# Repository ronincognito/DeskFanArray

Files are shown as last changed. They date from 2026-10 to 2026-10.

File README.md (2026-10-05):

# DeskFanArray

A 3D-printed bar of six PWM case fans, driven by an ESP32-S3 with a built-in touch display. Pick an airflow pattern on the screen, such as a gentle breeze, a travelling wave or a pulse, and the fans do the rest.

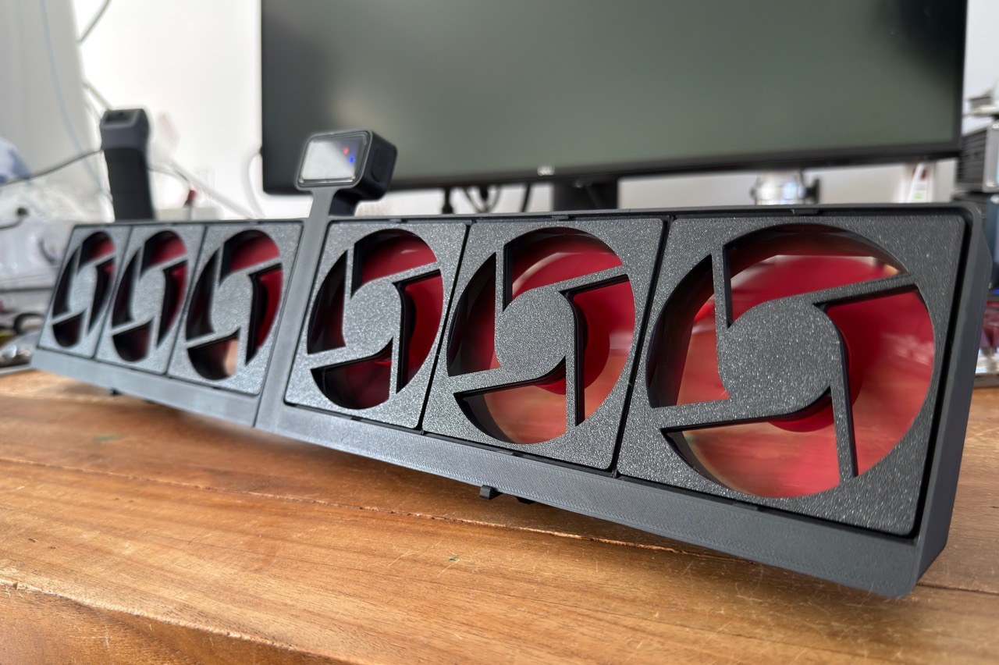
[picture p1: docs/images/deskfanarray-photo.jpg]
The finished DeskFanArray


Full project document (wiring, UI design, parts): [docs/README.pdf](docs/README.pdf)

## Features

- **Six 80 mm fans** with independent PWM speed control (any PWM fan works)
- **Touch UI** on a Waveshare ESP32-S3 1.47" display board, with seven screens, one per mode
- **Fully 3D-printed housing**, designed in Fusion 360
- **Single 12 V input** (match your fans' voltage); a buck converter makes the 5 V for the controller
- **Arduino firmware** with a configurable startup screen

## Control UI

The display has seven screens, one per mode. The dots at the bottom show which screen you are on. The six grey bars mirror the current speed of each fan; the coloured controls set the parameters of the active mode.

| breeze | wave |
|---|---|
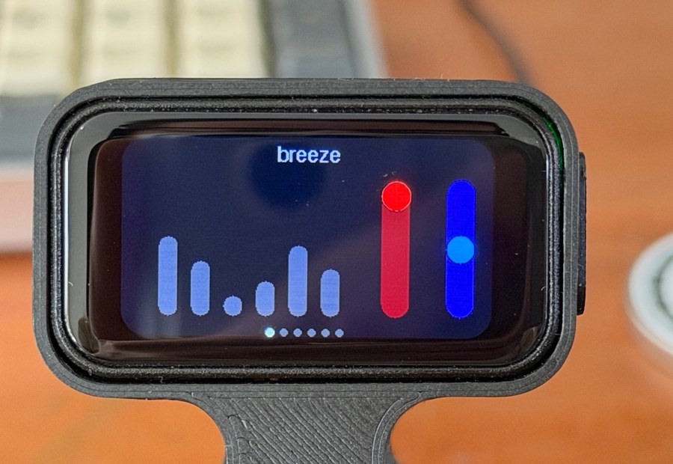
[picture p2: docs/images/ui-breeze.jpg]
breeze screen
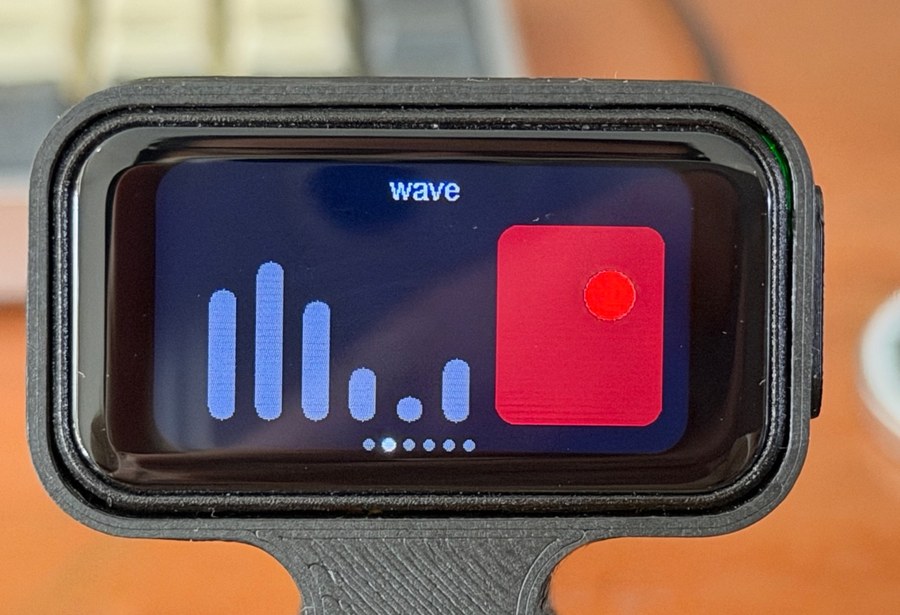
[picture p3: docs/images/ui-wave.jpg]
wave screen
|  |  |

| Screen | Controls |
|---|---|
| breeze | Two sliders: *peak gust* (red) and *gustiness* (blue) |
| wave | 2D pad for *wave height* and *direction* |
| monotone | One slider sets all fans to the same speed |
| stereotone | Two sliders, one for each half of the array |
| custom | Six sliders, one per fan |
| pulse | Two sliders (red and amber) for the pulsing pattern |

**Default screen:** press and hold (`longPress`) on a control screen to make it the default. On power-up, that screen is shown first.

The complete UI design sketch is in [docs/images/ui-overview.png](docs/images/ui-overview.png).

## Hardware

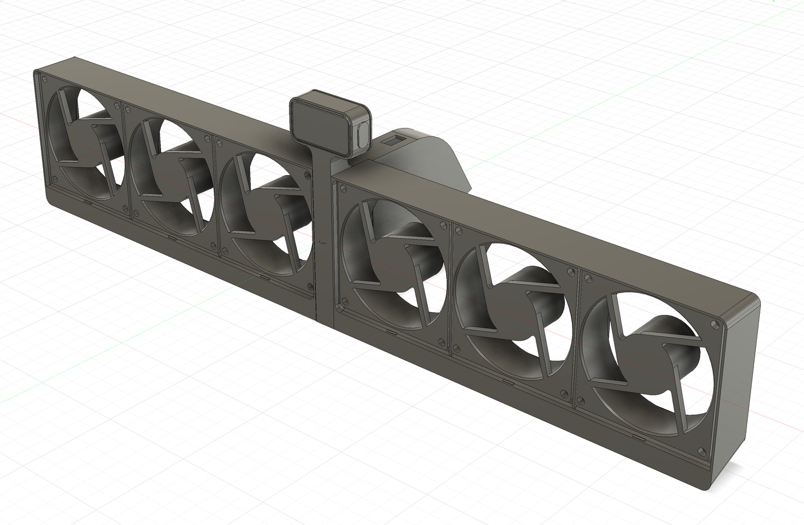
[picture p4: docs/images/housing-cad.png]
CAD model of the housing


| Part | Notes |
|---|---|
| ESP32-S3 touch LCD, 1.47" | Waveshare board; runs the UI and generates the six PWM signals |
| 6 x 80x80 mm PWM case fans | Xilence XPF80.R PWM in this build (12 V). Each fan's PWM wire goes to its own GPIO pin |
| Buck converter | 12 V in, 5 V out; powers the ESP board |
| 12 V DC supply | Powers the fans directly and the controller via the buck converter |
| On/off toggle switch | Mounted on the case behind the display; switches the +12 V line to both the buck converter and the fans |
| 3D-printed housing | Two case halves and a midsection, from the Fusion 360 model |
| 4 x M3 bolts + nuts | Mount the two case halves to the midsection |
| 4 x M2 bolts | Mount the controller to the midsection |

Any fan will do as long as it accepts a PWM input. If your fans need a voltage other than 12 V, adapt the supply voltage accordingly, and make sure the buck converter accepts that input voltage and still delivers 5 V to the controller.

## Wiring

The 12 V supply passes through the on/off toggle switch, which feeds the 12 V rail for the six fans and the buck converter. All fans share a common ground with the ESP board. The buck converter drops 12 V to 5 V for the controller, and six GPIO pins send PWM signals to the fans.

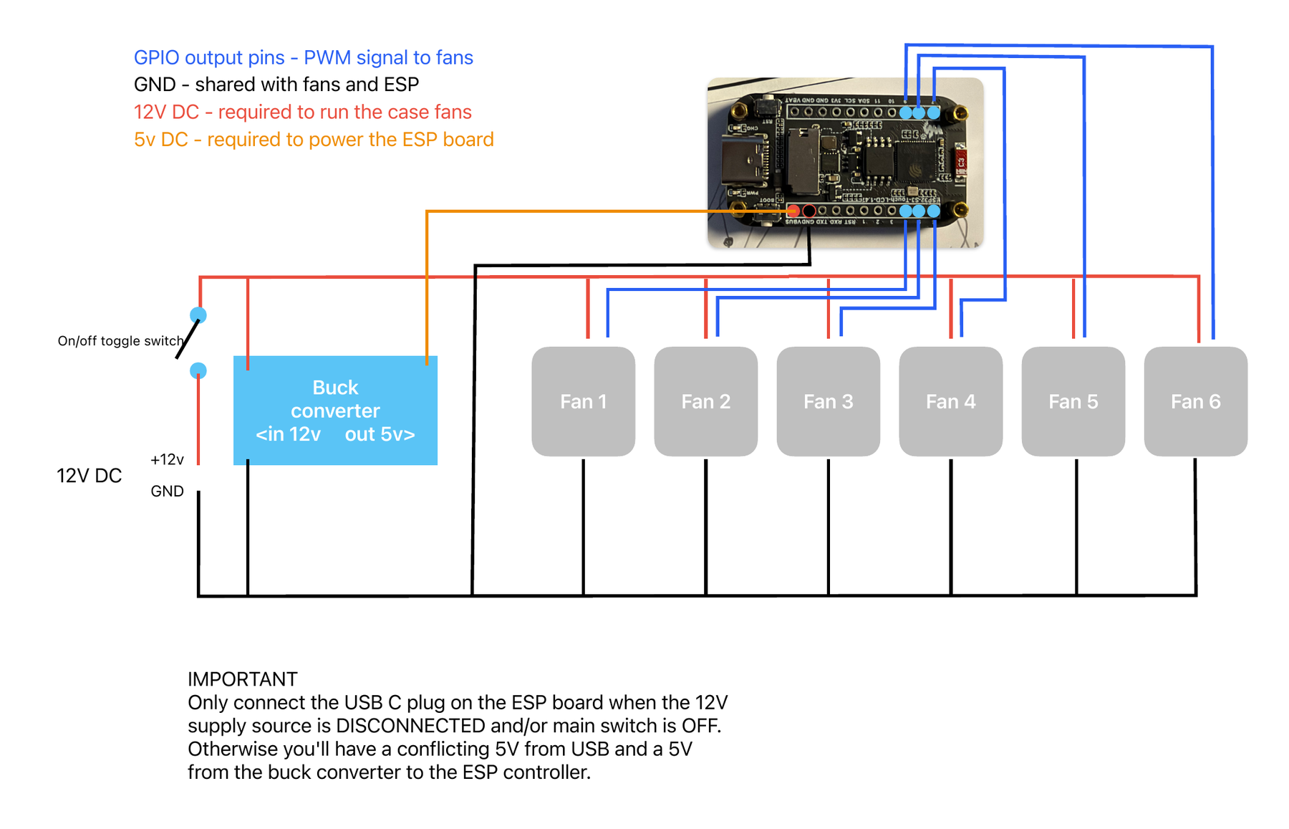
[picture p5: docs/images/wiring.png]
Wiring diagram


> **IMPORTANT:** Only connect the USB-C plug on the ESP board when the 12 V supply is disconnected and/or the main switch is OFF. Otherwise the board receives a conflicting 5 V from USB and from the buck converter.

## Repository layout

```
DeskFanArray/
  docs/                      wiring diagram, UI design, board photo, project PDF
  models/Fusion/             Fusion 360 housing model
  src/DeskFanController/
    DeskFanController.ino    firmware
    startup_image.h          startup image data
```

## Build and flash

1. Open `src/DeskFanController/DeskFanController.ino` in the Arduino IDE.
2. Select the Waveshare ESP32-S3 touch LCD 1.47" board (ESP32-S3 core) and the matching USB port.
3. Disconnect the 12 V supply (see the warning above), connect USB-C, and upload.
4. Disconnect USB, then power the unit from the 12 V supply.

## License

Released under the [MIT License](LICENSE). Copyright (c) 2026 ronincognito.

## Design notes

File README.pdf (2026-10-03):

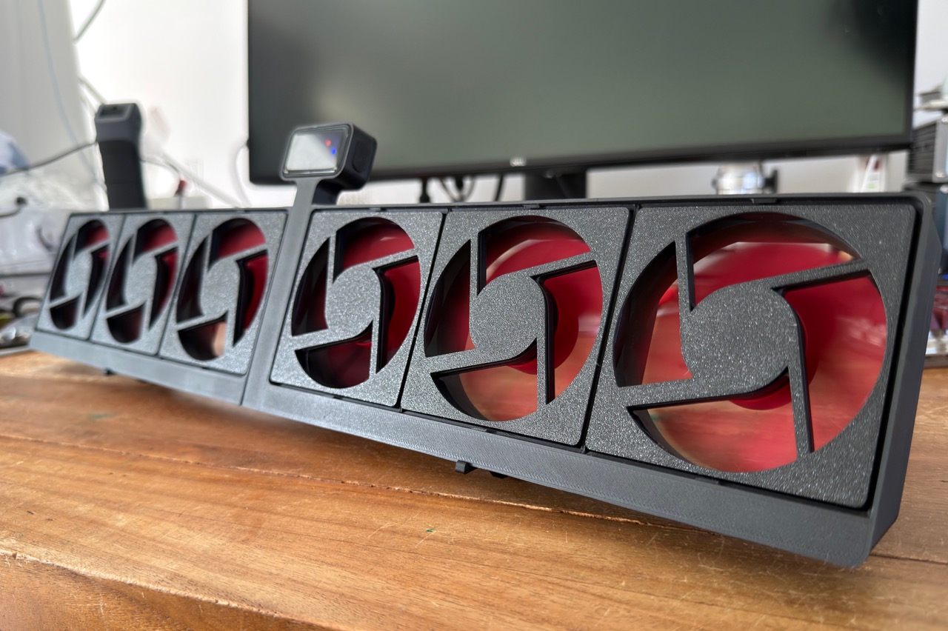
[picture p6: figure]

DeskFanArray | github.com/ronincognito/DeskFanArray | 1

# DeskFanArray

### A 3D-printed bar of six PWM case fans, driven by an ESP32-S3 with a built-in touch

display. Pick an airflow pattern on the screen, such as a gentle breeze, a travelling wave or a pulse, and the fans do the rest.

The finished build: six 12 V fans in a printed housing, with the controller display on a stalk in the middle.

## Overview

DeskFanArray combines six individually controlled fans in one long housing that sits on a desk. A small touch screen on a stalk lets you switch between control modes and adjust their parameters with sliders and a 2D pad. Each fan gets its own PWM signal, so patterns can move across the array instead of simply running all fans at the same speed.
- Six fans with independent PWM speed control (12 V case fans).
- Touch UI on a Waveshare ESP32-S3 1.47" display board, with seven screens, one per mode.
- Fully printed housing, designed in Fusion 360.
- Single 12 V input; a buck converter makes the 5 V for the controller.
- Arduino firmware (.ino) with a configurable startup screen.

## Control UI

The display shows seven screens, one per mode. The dots at the bottom show where you are. The six grey bars mirror the current speed of each fan. The red and blue controls set the parameters of the active mode.

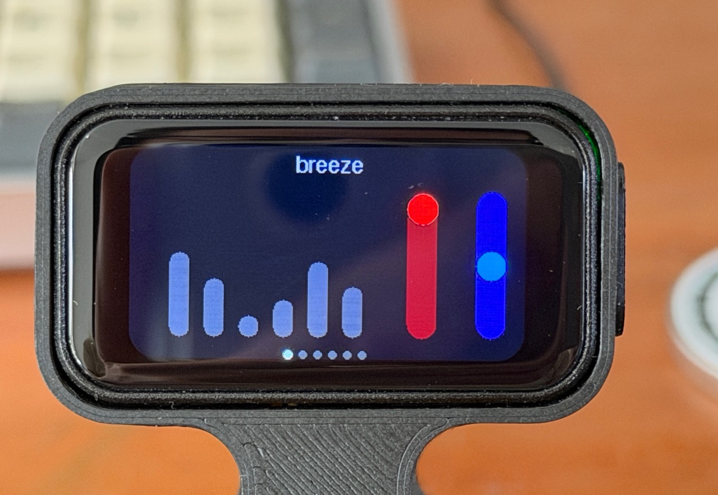
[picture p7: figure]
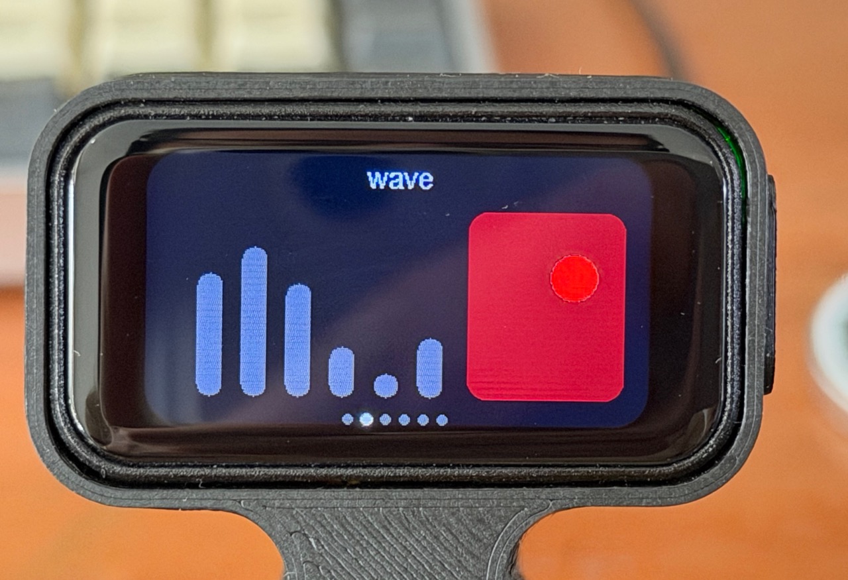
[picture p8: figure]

breeze: two sliders shape the airflow (red and blue). | wave: a 2D pad sets wave height and direction.
Screen | Controls (from the UI design)
breeze | Two sliders: peak gust (red) and gustiness (blue)
wave | 2D pad for wave height and direction; can be set as the startup screen
monotone | One slider sets all fans to the same speed
stereotone | Two sliders, one for each half of the array (left three, right three fans)
custom | Six sliders, one per fan
pulse | Two sliders (red and amber) for the pulsing pattern

Any screen can be chosen as the startup screen; the design on the next page shows wave set as the startup screen.

## UI design overview

Design sketch of all screens (Sketch file in docs/). Left column: breeze, wave, monotone, stereotone, custom, pulse. Right column: the wave startup-screen setting and the sub-screens for wave height/direction, peak gust and gustiness.

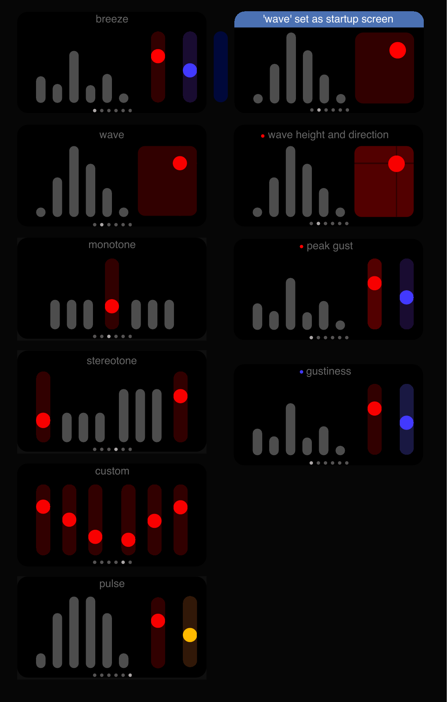
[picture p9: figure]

## Hardware

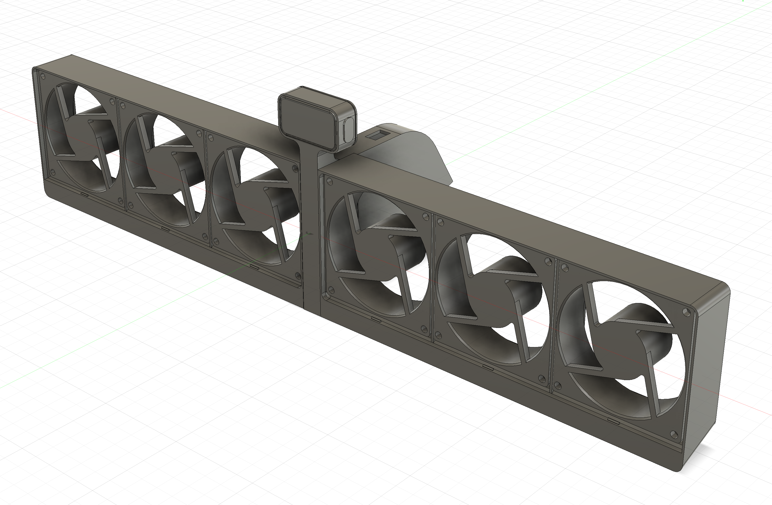
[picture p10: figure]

CAD model of the housing in Fusion 360 (file in models/Fusion/).

Part | Notes
ESP32-S3 touch LCD, 1.47" | Waveshare board; runs the UI and generates the six PWM signals
6 x 12 V PWM case fans | Each fan's PWM wire goes to its own GPIO pin
Buck converter | 12 V in, 5 V out; powers the ESP board
12 V DC supply + switch | Main switch on the +12 V line
3D-printed housing | Printed parts from the Fusion 360 model

## Wiring

All fans share the 12 V rail and a common ground with the ESP board. The buck converter drops 12 V to 5 V for the controller, and six GPIO pins send PWM signals to the fans.

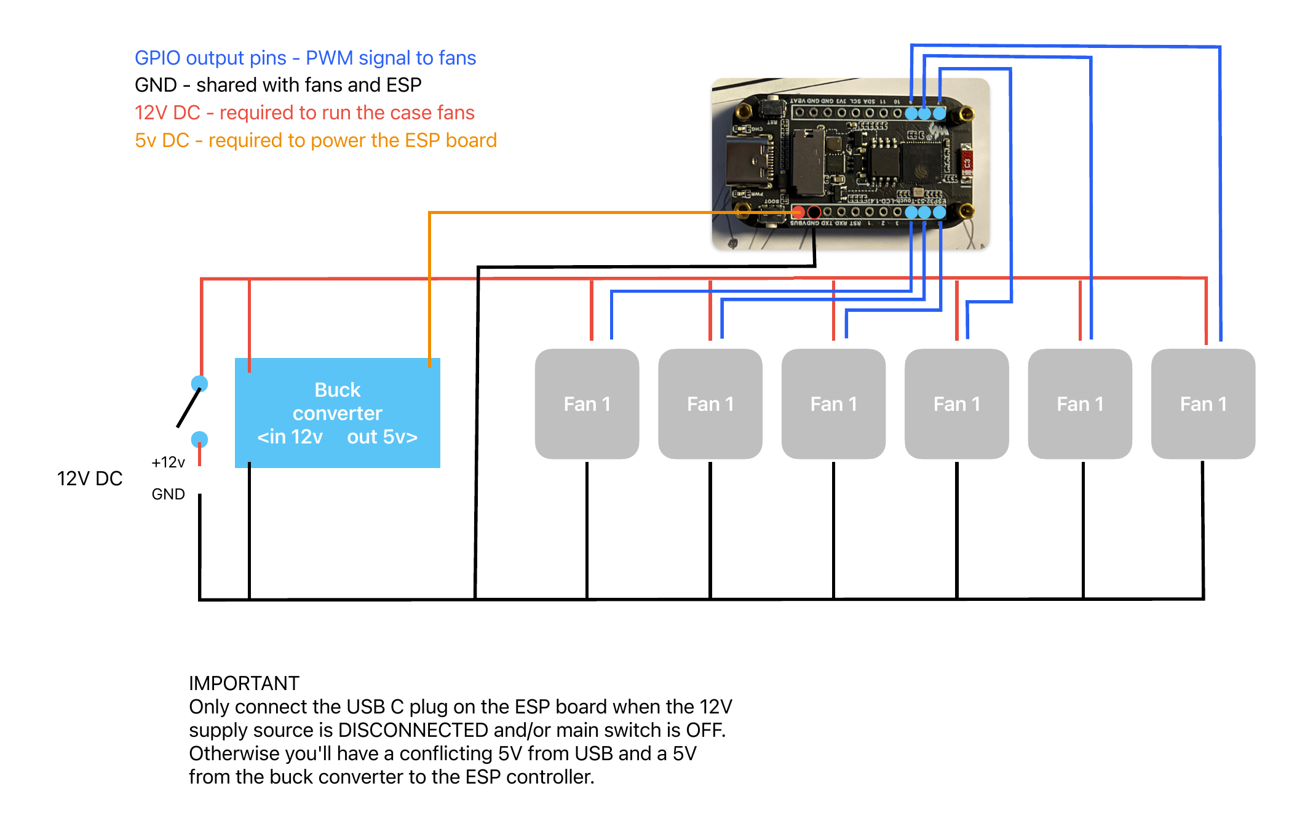
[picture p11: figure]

Wiring diagram (PDF in docs/). Blue: PWM signals. Black: ground. Red: 12 V. Orange: 5 V.

IMPORTANT
Only connect the USB-C plug on the ESP board when the 12 V supply is disconnected and/or the main switch is OFF. Otherwise the board receives a conflicting 5 V from USB and from the buck converter.

## Repository layout

DeskFanArray/
docs/ | wiring diagram, UI design (Sketch), board photo, notes
models/ | Fusion 360 housing model
src/DeskFanController/
DeskFanController.ino firmware
startup_image.h | startup image data

## Build and flash

- Open src/DeskFanController/DeskFanController.ino in the Arduino IDE.
- Select the Waveshare ESP32-S3 touch LCD 1.47" board (ESP32-S3 core) and the matching USB port.
- Disconnect the 12 V supply (see the warning above), connect USB-C, and upload.
- Disconnect USB, then power the unit from the 12 V supply.

Licence: not yet specified.

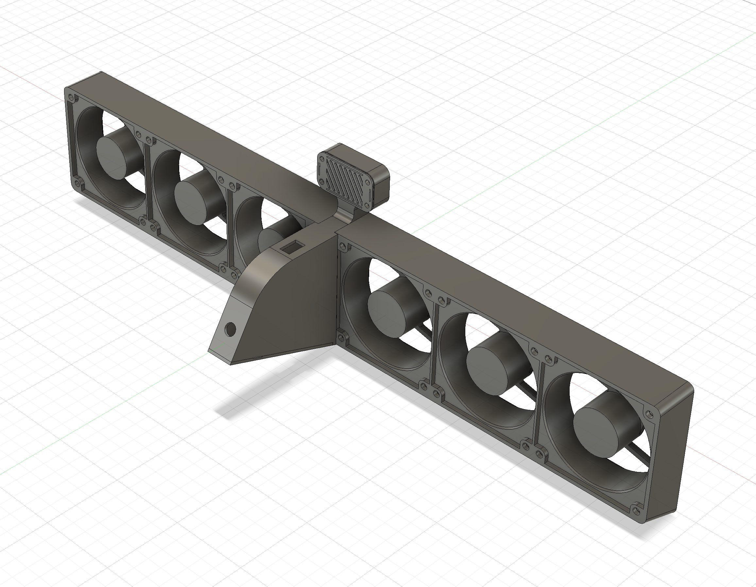
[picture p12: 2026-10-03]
docs/product design/Fusion Backside view.png

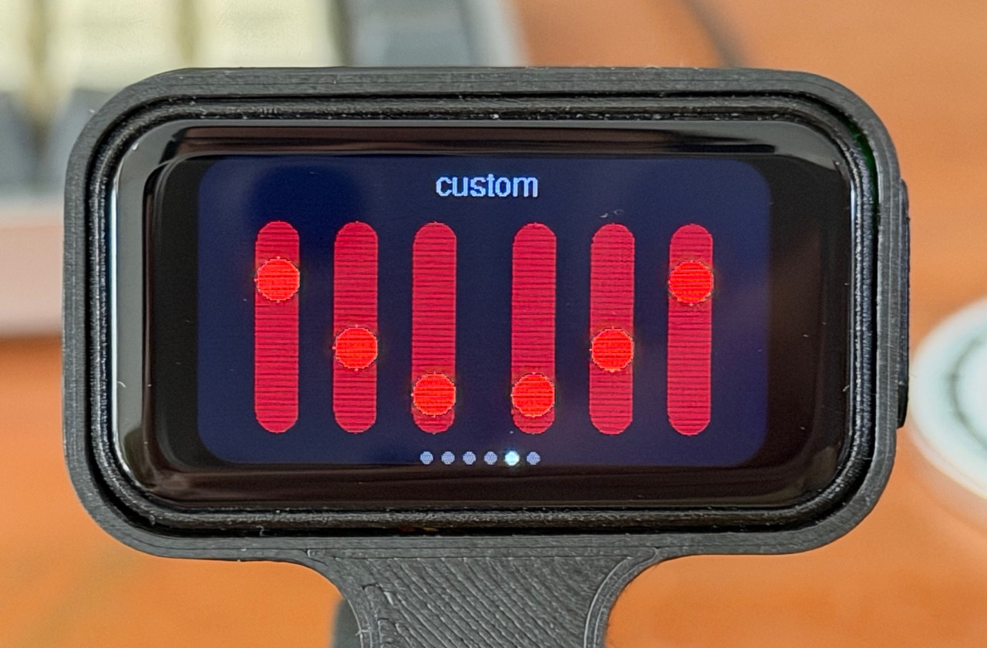
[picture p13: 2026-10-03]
docs/photos/IMG_6557 Large.jpeg

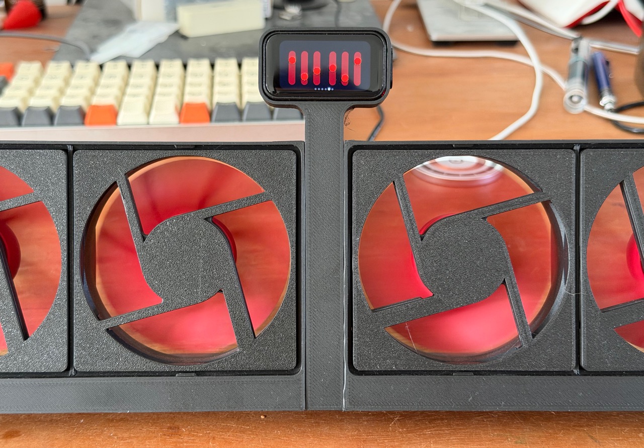
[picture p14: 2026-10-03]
docs/photos/IMG_6558 Large.jpeg

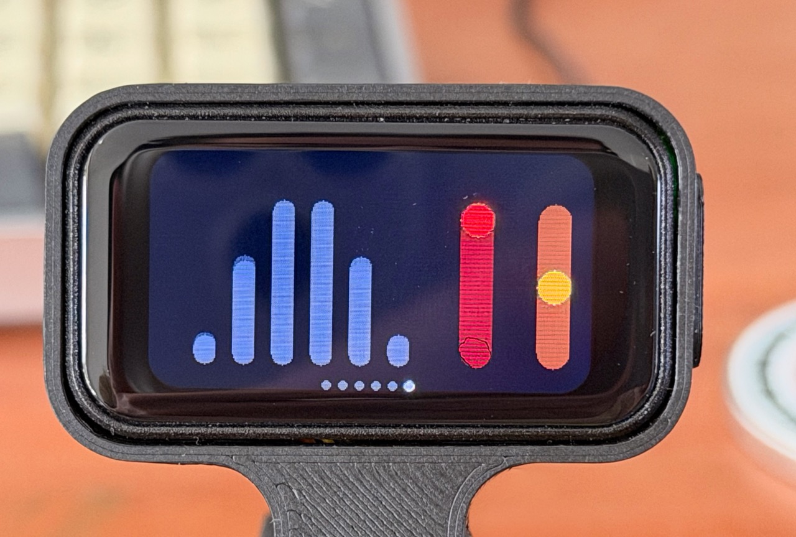
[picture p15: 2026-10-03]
docs/photos/IMG_6554 Large.jpeg

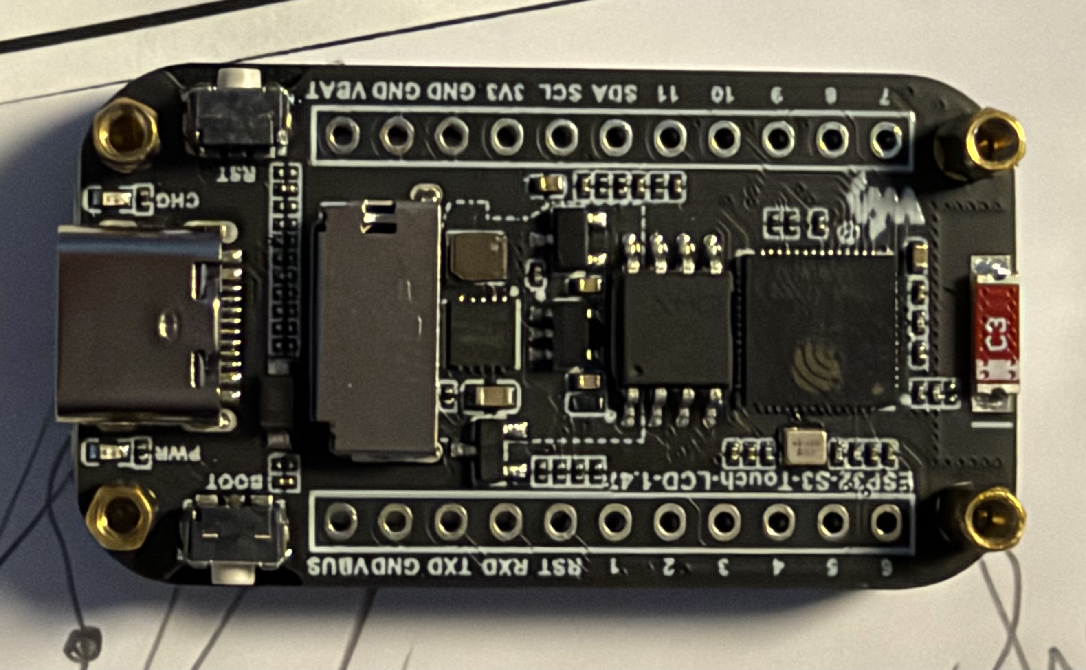
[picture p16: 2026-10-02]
docs/photos/Waveshare ESP32 S3 1.47 inch.jpeg

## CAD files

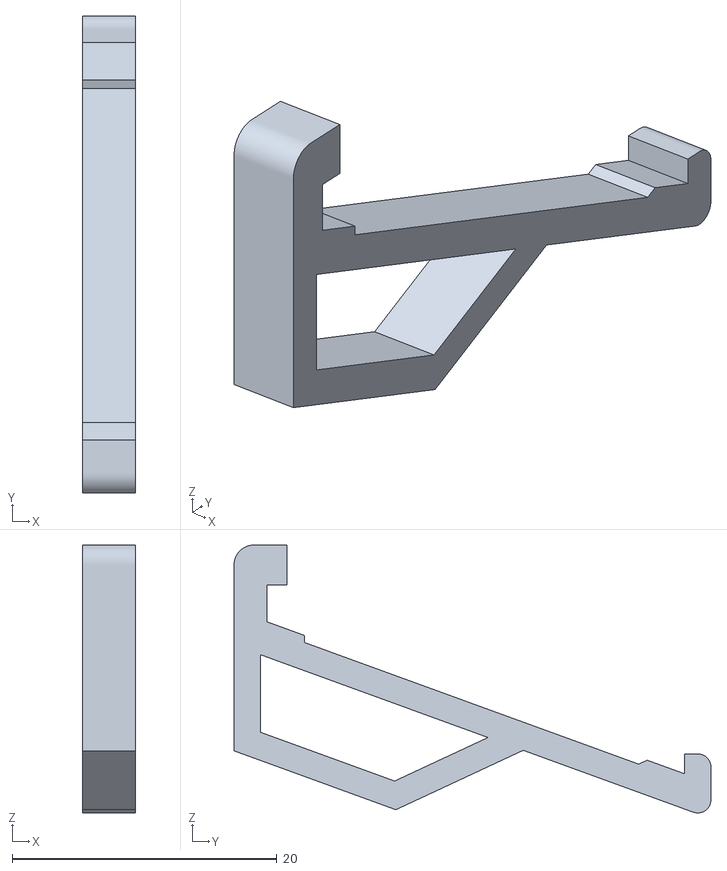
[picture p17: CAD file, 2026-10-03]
3D model/STL/support feet.stl
4.00 x 36.0 x 20.2

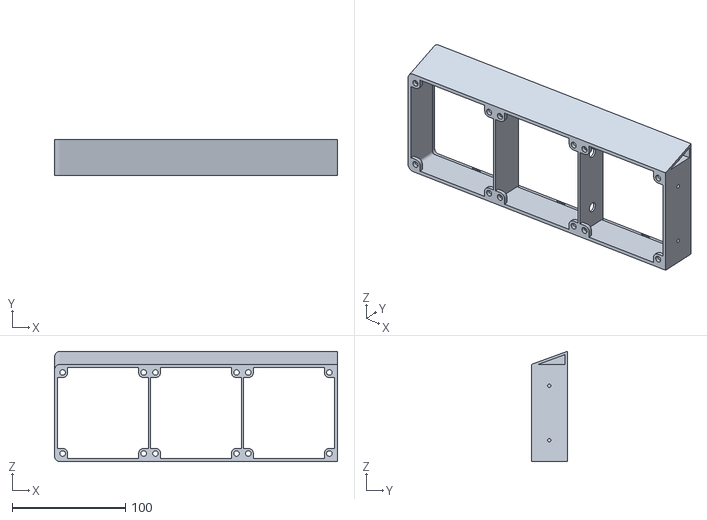
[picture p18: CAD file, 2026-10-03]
3D model/STL/case halve left side.stl
250.0 x 31.5 x 97.5

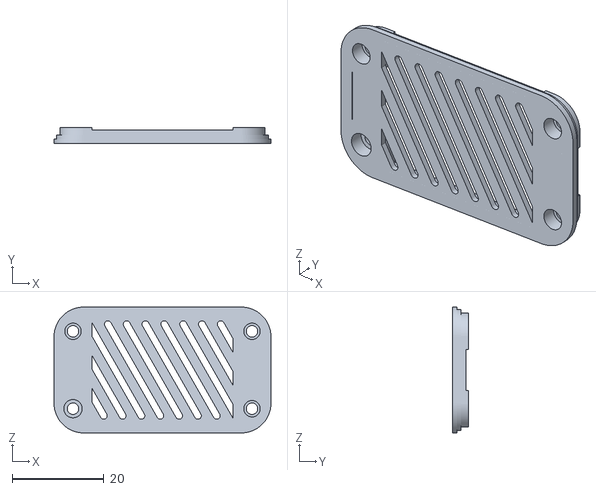
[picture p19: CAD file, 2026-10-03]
3D model/STL/case center cover backside controller.stl
47.4 x 3.51 x 27.5

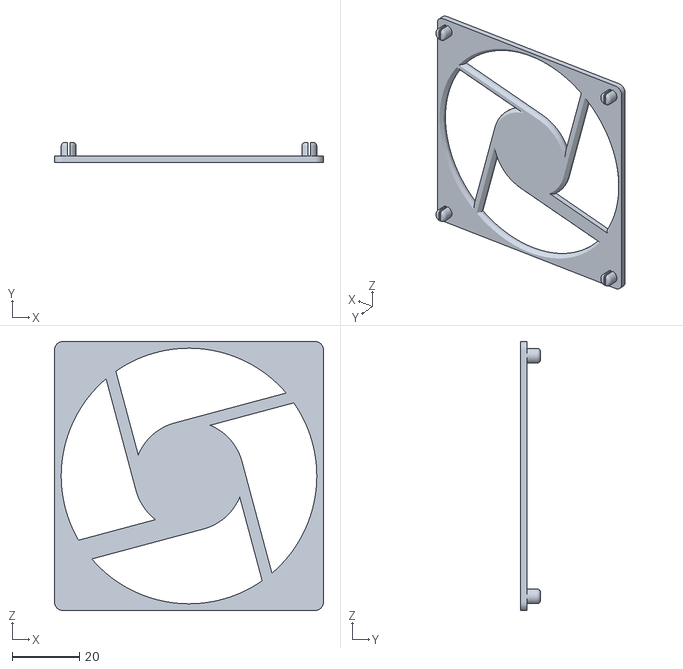
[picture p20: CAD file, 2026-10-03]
3D model/STL/case fan cover.stl
80.0 x 6.00 x 80.0

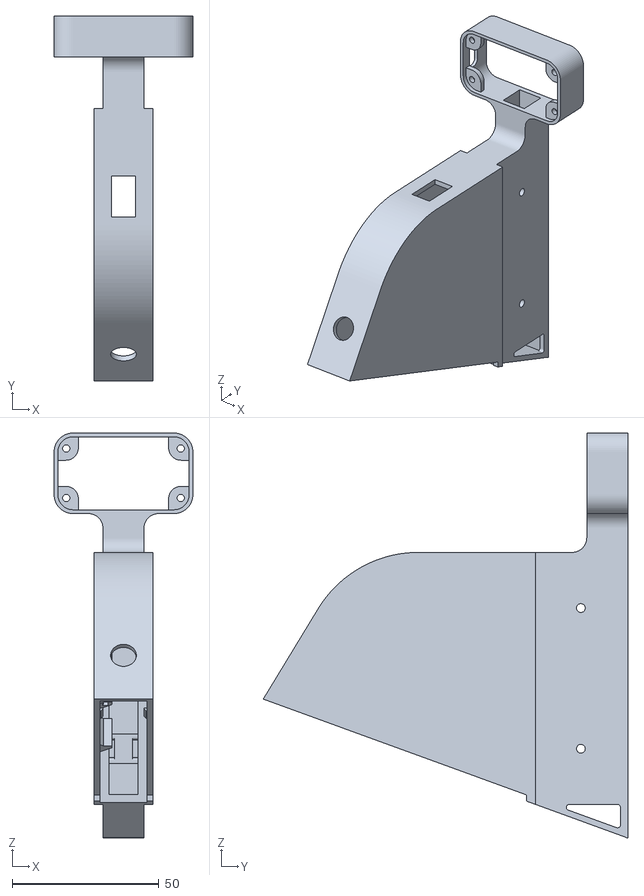
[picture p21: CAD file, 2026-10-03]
3D model/STL/case center part.stl
47.4 x 124.4 x 138.2

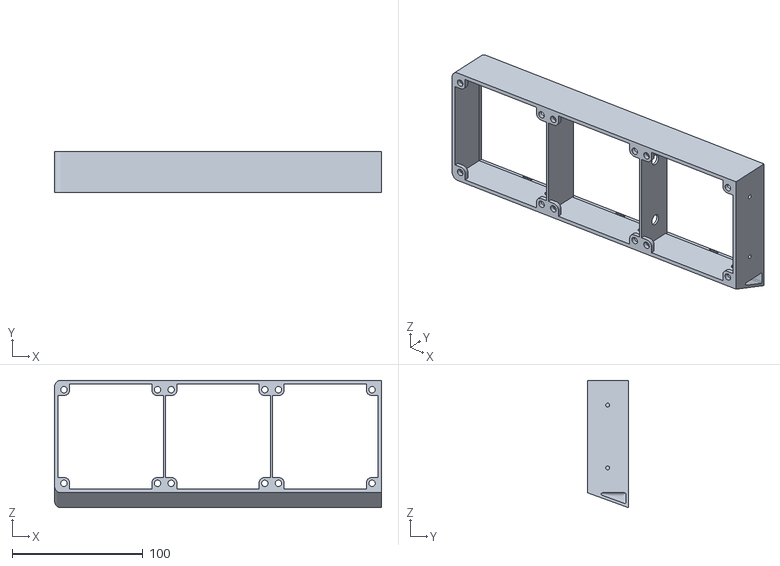
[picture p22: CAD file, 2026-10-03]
3D model/STL/case halve right side.stl
250.0 x 31.5 x 97.5

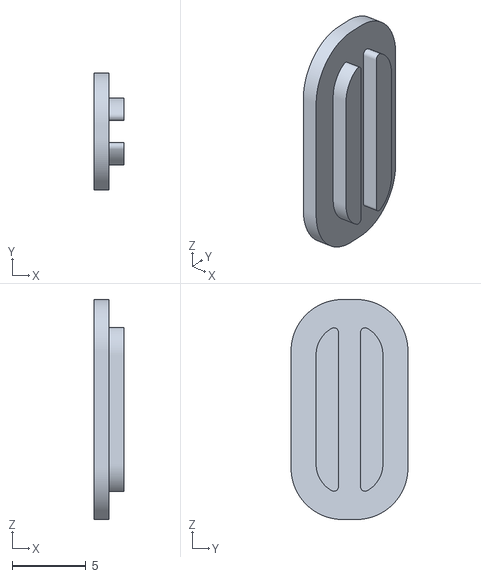
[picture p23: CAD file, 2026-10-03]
3D model/STL/case cover usb port.stl
2.00 x 7.92 x 14.9

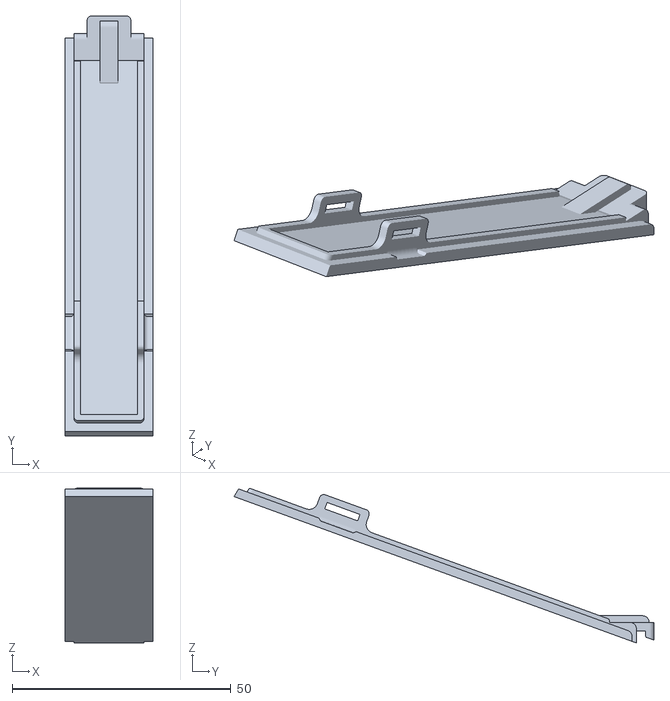
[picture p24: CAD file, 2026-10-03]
3D model/STL/case center bottom lid.stl
20.0 x 96.0 x 35.4

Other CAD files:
3D model/Fusion/Desk fan housing - Fusion 360.f3d

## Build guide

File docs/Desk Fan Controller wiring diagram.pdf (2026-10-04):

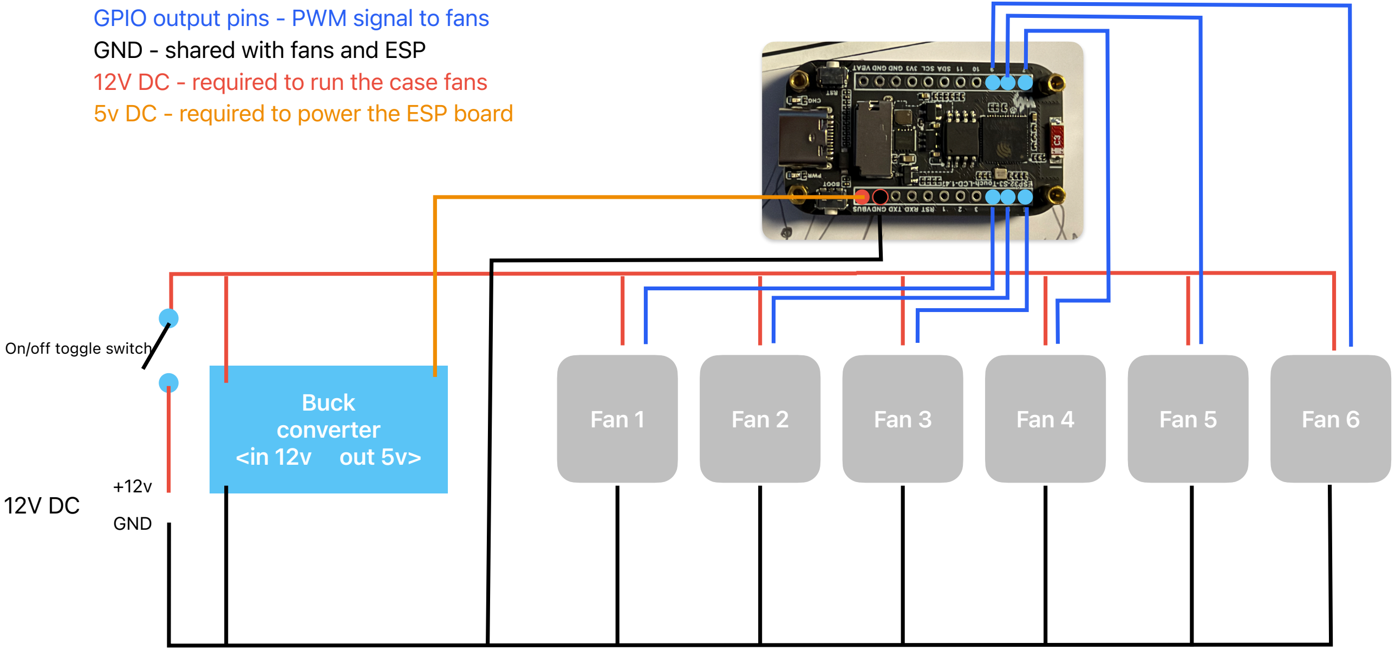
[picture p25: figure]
GND; Fan 1; Fan 2; Fan 3; Fan 4; Fan 5; Fan 6 Buck; converter <in 12v out 5v>; GPIO output pins - PWM signal to fans GND - shared with fans and ESP 12V DC - required to run the case fans 5v DC - required to power the ESP board; On/off toggle switch

IMPORTANT
Only connect the USB C plug on the ESP board when the 12V supply source is DISCONNECTED and/or main switch is OFF. Otherwise you'll have a conflicting 5V from USB and a 5V from the buck converter to the ESP controller.

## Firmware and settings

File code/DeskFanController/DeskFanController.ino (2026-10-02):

// ================================================================
// WaveShare Fan Controller — 6-fan PWM controller with touchscreen UI
// 5 swipeable screens: Custom, Stereotone, Monotone, Wave, Breeze, Pulse
// compile for board: Waveshare ESP32-S3-LCD-1.47
// ================================================================

#include <Arduino_GFX_Library.h>
#include <Wire.h>
#include "nvs_flash.h"
#include "nvs.h"
#include "esp_lcd_touch_axs5106l.h"
#include <Adafruit_GFX.h>
#include "Fonts/FreeSans9pt7b.h"
#include "startup_image.h"
#include "esp_heap_caps.h"
#include <string.h>

// ================================================================
// HARDWARE PINS
// ================================================================

#define ROTATION 1
#define DISPLAY_SPI_SPEED 40000000 // default (unspecified) is much more conservative; try 80000000
                                    // if wiring is short/clean and the panel stays glitch-free
#define FORCE_WIPE_TRANSITION 0    // diagnostic only: set to 1 to disable the push transition
                                    // entirely (falls back to the old wipe) without removing any
                                    // code, to isolate whether a crash is coming from that path
#define GFX_BL 46
#define LCD_RST 40
#define PWM_FREQ 25000
#define PWM_RESOLUTION 8
#define TOUCH_SDA 42
#define TOUCH_SCL 41
#define TOUCH_RST 47
#define TOUCH_INT 48

#define NUM_FANS 6
const int FAN_PINS[NUM_FANS] = { 4, 5, 6, 7, 8, 9 };

Arduino_DataBus *bus = new Arduino_ESP32SPI(45, 21, 38, 39);
Arduino_GFX *gfx = new Arduino_ST7789(bus, 47, 0, false, 172, 320, 34, 0, 34, 0);

// Screen layout constants needed by initPushTransition() below (moved up
// from the SHARED LAYOUT section, which is further down the file, since
// TRANSITION_HEIGHT is needed before that point).
#define TITLE_Y -2
#define DOTS_Y 168 // position page dots

// Content band animated by the push transition (see pushTransition()) --
// deliberately excludes the title strip and the page-dot row, which stay
// static during the slide instead of moving with the content.
#define TRANSITION_TOP    30                                // just below the title strip
#define TRANSITION_HEIGHT (DOTS_Y - 4 - TRANSITION_TOP)      // stop a few px above the page dots

// ================================================================
// PSRAM-BACKED OFF-SCREEN CANVAS (used for the push-transition animation)
// ================================================================
// Arduino_Canvas's own begin() allocates its framebuffer with
// aligned_alloc() (verified against the library source), which on ESP32
// comes out of internal RAM, not PSRAM. A push transition needs two full
// 320x172 16-bit screen buffers (rendering happens at full-screen
// coordinates, since the existing draw*Screen() functions use absolute
// y positions like BAR_TOP/DOTS_Y) plus one smaller composite buffer --
// more than internal RAM can comfortably spare -- so this subclass
// overrides begin() to force the framebuffer into PSRAM via
// heap_caps_malloc(). Everything else (drawing primitives, text, flush())
// is inherited unchanged from Arduino_Canvas.
class Arduino_CanvasPSRAM : public Arduino_Canvas {
 public:
  Arduino_CanvasPSRAM(int16_t w, int16_t h, Arduino_G *output)
    : Arduino_Canvas(w, h, output) {}

  bool begin(int32_t speed = GFX_NOT_DEFINED) override {
    if (!_framebuffer) {
      size_t s = (size_t)_width * _height * 2;
      _framebuffer = (uint16_t *)heap_caps_malloc(s, MALLOC_CAP_SPIRAM);
      if (!_framebuffer) return false;
    }
    return true; // the real gfx/output is already begin()'d elsewhere in setup()
  }
};

// Two off-screen canvases (outgoing / incoming screen) plus one composite
// buffer that gets blitted to the real display once per animation frame.
// Allocated in initPushTransition() (called from setup()); transitionReady
// stays false — and goToScreen() falls back to the plain wipe — if PSRAM
// wasn't available for any reason.
Arduino_CanvasPSRAM *transitionCanvasOld = nullptr;
Arduino_CanvasPSRAM *transitionCanvasNew = nullptr;
uint16_t *transitionComposite = nullptr;
bool transitionReady = false;

void initPushTransition() {
  transitionCanvasOld = new Arduino_CanvasPSRAM(gfx->width(), gfx->height(), gfx);
  transitionCanvasNew = new Arduino_CanvasPSRAM(gfx->width(), gfx->height(), gfx);
  // Only the content band (TRANSITION_HEIGHT rows) is ever composited/blitted per
  // frame -- the title strip and page dots stay static -- so the composite
  // buffer only needs to be that tall, not a full screen height.
  transitionComposite = (uint16_t *)heap_caps_malloc((size_t)gfx->width() * TRANSITION_HEIGHT * 2, MALLOC_CAP_SPIRAM);

  transitionReady = transitionCanvasOld->begin() && transitionCanvasNew->begin() && (transitionComposite != nullptr);
  if (!transitionReady) {
    Serial.println("Push transition: PSRAM allocation failed, falling back to wipe transition.");
  }
}

// ================================================================
// BACKLIGHT (idle dim/off + transition fade)
// ================================================================

#define BACKLIGHT_PWM_FREQ       5000
#define BACKLIGHT_PWM_RESOLUTION 8
#define BACKLIGHT_FULL  255
#define BACKLIGHT_DIM   80
#define BACKLIGHT_OFF   0
#define IDLE_DIM_MS   120000   // dim after 2 min of no touch
#define IDLE_OFF_MS   600000  // fully off after 10 min of no touch
#define STARTUP_BACKLIGHT_DELAY_MS 500 // hold backlight off this long after the splash screen is
                                        // drawn, before fading in (tune to taste)
#define STARTUP_SCREEN_HOLD_MS 2000    // roughly how long the splash stays fully visible before
                                        // wiping into the default screen (measured from when
                                        // drawStartupScreen() runs; doesn't separately account
                                        // for the ~150ms fade-in/out on top of this)

unsigned long lastActivityTime = 0;
int currentBacklight = BACKLIGHT_OFF; // starts OFF — see setup(), which kills the backlight in
                                       // hardware before this variable's initial value even matters

void setBacklight(int level) {
  if (level != currentBacklight) {
    currentBacklight = level;
    ledcWrite(GFX_BL, level);
  }
}

// Fades the backlight linearly from wherever it currently is up to
// BACKLIGHT_FULL, over `steps` increments spaced `stepDelayMs` apart.
// Shared by the startup fade-in (setup()) and every screen transition
// (goToScreen()) so there's one fade implementation, not two.
void fadeBacklightIn(int steps = 10, int stepDelayMs = 15) {
  for (int i = 1; i <= steps; i++) {
    setBacklight((i * BACKLIGHT_FULL) / steps);
    delay(stepDelayMs);
  }
}

// Mirror of fadeBacklightIn(): fades the backlight linearly down to
// BACKLIGHT_OFF instead of up to BACKLIGHT_FULL. Used for the startup
// splash -> default screen transition (dim to black, draw, fade back in)
// rather than a wipe.
void fadeBacklightOut(int steps = 10, int stepDelayMs = 15) {
  for (int i = steps - 1; i >= 0; i--) {
    setBacklight((i * BACKLIGHT_FULL) / steps);
    delay(stepDelayMs);
  }
}

// ================================================================
// COLORS
// ================================================================

#define RGB565(r, g, b) (((r) << 11) | ((g) << 5) | (b))
#define GREY565(level5bit) RGB565((level5bit), (level5bit) * 2, (level5bit))

#define COLOR_BAR_BG              RGB565(6, 0, 0)
#define COLOR_BAR_BG_ACTIVE       RGB565(10, 0, 0)   // lighter/warmer red-track when being dragged
#define COLOR_BAR_FILL            RGB565(31, 0, 0)   // full-bright red, in this file's own 5/6/5-bit
                                                      // RGB565() scale -- NOT the library's RGB565_RED,
                                                      // which assumes 8-bit inputs and silently
                                                      // overflowed uint16_t when this file's RGB565()
                                                      // macro (redefined above, 5/6/5-bit) re-expanded
                                                      // it; harmless via implicit truncation in a plain
                                                      // assignment, but a hard narrowing error once used
                                                      // inside a brace-initializer (see Control struct)

#define COLOR_DOT_ACTIVE          GREY565(16)
#define COLOR_DOT_INACTIVE        GREY565(4)
#define COLOR_CONTROL_BG          COLOR_BAR_BG
#define COLOR_CONTROL_DOT         COLOR_BAR_FILL
#define COLOR_CONTROL_CROSSHAIR   RGB565(6, 0, 0) // faint crosshair through the pad's thumb
#define CROSSHAIR_WIDTH           2

#define COLOR_WAVE_BAR            GREY565(4)

#define COLOR_BLUE_BAR_BG         RGB565(3, 3, 6)
#define COLOR_BLUE_BAR_BG_ACTIVE  RGB565(3, 6, 8)
#define COLOR_BLUE_BAR_FILL       RGB565(8, 14, 31)

#define COLOR_YELLOW_BAR_BG   RGB565(6, 6, 1)   // dark yellow track
#define COLOR_YELLOW_BAR_BG_ACTIVE RGB565(10, 10, 0)
#define COLOR_YELLOW_BAR_FILL RGB565(24, 24, 3)   // bright yellow thumb

#define COLOR_CONTROL_BG_ACTIVE   COLOR_BAR_BG_ACTIVE // Ondulation's pad, same treatment as (red) bar

// ================================================================
// SCREENS
// ================================================================

#define SCREEN_NATURAL_BREEZE 0
#define SCREEN_ONDULATION     1
#define SCREEN_MONOTONE       2
#define SCREEN_STEREOTONE     3
#define SCREEN_CUSTOM         4
#define SCREEN_PULSE          5
#define NUM_SCREENS           6

const char *SCREEN_TITLES[NUM_SCREENS] = {
  "breeze", "wave", "monotone", "stereotone", "custom", "pulse"
};

int currentScreen = SCREEN_CUSTOM; // placeholder — setup() overwrites this with the persisted default

// ================================================================
// PERSISTED DEFAULT SCREEN — which screen to boot into, saved across
// power cycles via a long press (see onLongPress() below) and read back
// in setup(). Uses the ESP-IDF NVS API directly (nvs_flash.h/nvs.h)
// rather than the Arduino `Preferences` wrapper: same underlying flash
// storage, but Preferences.h failed to resolve on at least one setup
// despite a core new enough to have it (this sketch already relies on
// the core-3.x single-pin ledcAttach() API elsewhere) — likely a stale
// library-index/cache issue rather than a missing core. nvs_flash.h and
// nvs.h are core ESP-IDF headers, resolved through a different, more
// fundamental include path than Arduino's per-sketch library search, so
// they sidestep whatever was going wrong with the Preferences library
// specifically.
// ================================================================

#define NVS_NAMESPACE "fanctrl"
#define NVS_KEY_DEFAULT_SCREEN "defScreen"

bool nvsReady = false; // set in initNvs(); load/save below silently no-op if NVS never came up

// Initializes the NVS flash partition. Must be called once, early in
// setup(), before loadDefaultScreen()/saveDefaultScreen() are used.
// Handles the two known first-boot conditions (no free pages / a newer
// NVS layout than what's currently written) by erasing and retrying —
// standard ESP-IDF boilerplate for this call.
void initNvs() {
  esp_err_t err = nvs_flash_init();
  if (err == ESP_ERR_NVS_NO_FREE_PAGES || err == ESP_ERR_NVS_NEW_VERSION_FOUND) {
    nvs_flash_erase();
    err = nvs_flash_init();
  }
  nvsReady = (err == ESP_OK);
  if (!nvsReady) Serial.println("NVS init failed; default-screen persistence disabled for this session");
}

// Reads the persisted default screen, falling back to Natural Breeze if
// NVS isn't available, nothing has been saved yet, or the stored value is
// out of range (e.g. a saved index from a build with more screens than
// this one has).
int loadDefaultScreen() {
  if (!nvsReady) return SCREEN_NATURAL_BREEZE;

  nvs_handle_t h;
  if (nvs_open(NVS_NAMESPACE, NVS_READONLY, &h) != ESP_OK) return SCREEN_NATURAL_BREEZE;

  uint8_t saved = SCREEN_NATURAL_BREEZE;
  nvs_get_u8(h, NVS_KEY_DEFAULT_SCREEN, &saved); // leaves `saved` at the fallback if the key doesn't exist yet
  nvs_close(h);

  return (saved < NUM_SCREENS) ? saved : SCREEN_NATURAL_BREEZE;
}

// Persists `screen` as the screen to boot into next time. Called from
// onLongPress() with the currently shown screen.
void saveDefaultScreen(int screen) {
  if (!nvsReady) return;

  nvs_handle_t h;
  if (nvs_open(NVS_NAMESPACE, NVS_READWRITE, &h) != ESP_OK) return;

  nvs_set_u8(h, NVS_KEY_DEFAULT_SCREEN, (uint8_t)screen);
  nvs_commit(h);
  nvs_close(h);
}

// ================================================================
// STARTUP DEFAULTS — edit these to change what each screen
// starts up showing/driving, without touching logic elsewhere
// ================================================================

#define DEFAULT_CUSTOM_DUTY1 200
#define DEFAULT_CUSTOM_DUTY2 100
#define DEFAULT_CUSTOM_DUTY3 30
#define DEFAULT_CUSTOM_DUTY4 30
#define DEFAULT_CUSTOM_DUTY5 100
#define DEFAULT_CUSTOM_DUTY6 200

#define DEFAULT_MONOTONE_DUTY     60
#define DEFAULT_STEREO_LEFT_DUTY  50
#define DEFAULT_STEREO_RIGHT_DUTY 80
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
void loop() {
  touch_data_t touch_data;
  bsp_touch_read();
  bool touched = bsp_touch_get_coordinates(&touch_data);

  if (touched) lastActivityTime = millis(); // any touch resets the idle-dim timer

  // ---- Per-screen continuous animation (runs regardless of touch) ----
  if (screens[currentScreen].update) {
    static unsigned long lastFrame = 0;
    unsigned long now = millis();
    if (now - lastFrame >= 40) {
      lastFrame = now;
      screens[currentScreen].update();
    }
  }

  // ---- Title auto-hide (skipped while guidance text is showing) ----
  if (!guidanceActive && titleVisible && millis() - titleShownAt >= TITLE_DURATION_MS) {
    hideTitle();
  }

  // ---- Message auto-hide (e.g. the long-press confirmation) ----
  if (messageActive && millis() - messageShownAt >= MESSAGE_DURATION_MS) {
    hideMessage();
  }

  // ---- Backlight idle dim/off ----
  unsigned long idleTime = millis() - lastActivityTime;
  if (idleTime >= IDLE_OFF_MS) setBacklight(BACKLIGHT_OFF);
  else if (idleTime >= IDLE_DIM_MS) setBacklight(BACKLIGHT_DIM);
  else setBacklight(BACKLIGHT_FULL);

  // ================================================================
  // TOUCH HANDLING
  //
  // Structure:
  //   if (touched)
  //     if (!touchWasDown)   -> FRESH TOUCH-DOWN: identify which zone/bar
  //                             was hit for this screen, remember it in
  //                             activeFan/activeControl. Do NOT show
  //                             guidance or commit to a gesture yet — we
  //                             don't know if this will turn into a swipe
  //                             (finger moves mostly sideways) or a control
  //                             drag (finger moves mostly up/down) until the
  //                             finger actually moves.
  //                             EXCEPTION: Ondulation's pad commits to
  //                             GESTURE_PAD_DRAG immediately, since it's a
  //                             2D control — see note below.
  //     else                 -> CONTINUING TOUCH (finger still down):
  //       if GESTURE_PAD_DRAG   -> update the Ondulation dot directly
  //       else
  //         if GESTURE_NONE      -> resolve the gesture once movement
  //                                 crosses GESTURE_THRESHOLD: horizontal
  //                                 movement wins -> GESTURE_SWIPE (navigate
  //                                 immediately); vertical movement on a
  //                                 screen with an active zone -> GESTURE_DRAG
  //                                 (and show that zone's guidance text).
  //                                 If GESTURE_THRESHOLD is never crossed and
  //                                 LONG_PRESS_MS elapses instead -> GESTURE_
  //                                 LONG_PRESS (see onLongPress(); works
  //                                 anywhere on screen, not tied to a zone —
  //                                 the pad exception above means it doesn't
  //                                 currently apply inside Ondulation's pad).
  //         if GESTURE_DRAG       -> apply the accumulated vertical delta
  //                                 to whichever duty variable is active
  //                                 for this screen, redraw only what changed
  //   else (not touched)
  //     if touchWasDown was true -> touch just ended: reset all "active"
  //                                 state and hide any guidance text
  //
  // Custom (activeFan) and the Control-table screens (activeControl) each
  // get one branch below wherever the structure above calls for
  // screen-specific behavior; Custom's is still hand-written (per-bar
  // zone lookup via getFanZoneForTouch), everything else goes through the
  // generic Control table.
  //
  // NOTE on Ondulation's pad: unlike every other screen, the pad is a
  // genuine 2D control — a horizontal drag inside it means "change wave
  // direction", not "swipe to another screen". So a touch starting inside
  // the pad's bounds can NEVER become a swipe; it always becomes
  // GESTURE_PAD_DRAG immediately at touch-down. This is intentional: the
  // pad area is simply not swipeable, by design. Swiping out of the
  // Ondulation screen must start from outside the pad (e.g. from the grey
  // feedback bars on the left).
  // ================================================================

  if (touched) {
    int tx = touch_data.coords[0].x;
    int ty = touch_data.coords[0].y;

    if (!touchWasDown) {
      // ---- FRESH TOUCH-DOWN: zone detection only, no gesture decided yet ----
      touchStartX = tx;
      touchStartY = ty;
      touchStartTime = millis();
      lastTouchY = ty;
      currentGesture = GESTURE_NONE;
      ondulationGreyTouch = false;
      padDragYOnly = false;

      if (currentScreen == SCREEN_CUSTOM) {
        activeFan = getFanZoneForTouch(tx);

      } else if (numControls[currentScreen] > 0) {
        // Generic zone lookup for Monotone/Stereotone/Natural Breeze/Pulse.
        activeControl = -1;
        for (int i = 0; i < numControls[currentScreen]; i++) {
          if (tx >= controls[currentScreen][i].xMin && tx < controls[currentScreen][i].xMax) {
            activeControl = i;
            break;
          }
        }

      } else if (currentScreen == SCREEN_ONDULATION &&
                 tx >= controlX &&
                 tx < controlX + CONTROL_W + PAD_TOUCH_MARGIN_RIGHT &&
                 ty >= controlY - PAD_TOUCH_MARGIN_OTHER &&
                 ty < controlY + CONTROL_H + PAD_TOUCH_MARGIN_OTHER) {
        // Ondulation's pad is a 2D control -> commits immediately, see note above.
        currentGesture = GESTURE_PAD_DRAG;
        lastTouchX = tx;
        lastTouchY = ty;
        showGuidance("wave height and direction", COLOR_CONTROL_DOT);
        drawControlPad(true); // trigger active-color redraw immediately

      } else if (currentScreen == SCREEN_ONDULATION && tx < controlX) {
        // Grey feedback-bar area, left of the pad: not committed yet (a
        // horizontal drag out here should still be able to swipe to another
        // screen) -- just remembered, and resolved to a Y-only pad drag
        // below once/if vertical movement wins past GESTURE_THRESHOLD.
        ondulationGreyTouch = true;
      }

    } else {
      // ---- CONTINUING TOUCH ----

      if (currentGesture == GESTURE_PAD_DRAG) {
        float prevDotX = dotX;
        float prevDotY = dotY;

        if (!padDragYOnly) dotX += tx - lastTouchX; // grey-zone drag: X (direction) stays untouched
        dotY += ty - lastTouchY;
        clampDot();

        if (dotX != prevDotX || dotY != prevDotY) {
          drawControlPad(true);
        }

        lastTouchX = tx;
        lastTouchY = ty;

      } else {
        int dx = tx - touchStartX;
        int dy = ty - touchStartY;

        // ---- Resolve swipe vs. drag, once movement crosses the threshold —
        // or, if it never does, resolve to a long press once enough time
        // has passed while still under the threshold. ----
        if (currentGesture == GESTURE_NONE) {
          if (abs(dx) > GESTURE_THRESHOLD || abs(dy) > GESTURE_THRESHOLD) {

            if (abs(dx) > abs(dy)) {
              // Dominant horizontal movement -> navigate, fire once
              currentGesture = GESTURE_SWIPE;
              goToScreen(dx < 0 ? +1 : -1);
              // activeFan/activeControl were set against the screen we just
              // navigated AWAY from, for the rest of this still-held touch
              // (a swipe doesn't release the finger). Left stale, they can
              // index into the NEW screen's controls[] with an index that
              // was never populated there -- e.g. touching Stereotone's
              // right zone (activeControl=1) then swiping to Monotone
              // (only controls[SCREEN_MONOTONE][0] is initialized) leaves
              // controls[SCREEN_MONOTONE][1].redraw as a null function
              // pointer, crashed into on release. Invalidate both now.
              activeFan = -1;
              activeControl = -1;

            } else if (currentScreen == SCREEN_CUSTOM && activeFan != -1) {
              currentGesture = GESTURE_DRAG;
              showGuidance("speed", COLOR_BAR_FILL);
              drawBar(activeFan, true);

            } else if (numControls[currentScreen] > 0 && activeControl != -1 && activeControl < numControls[currentScreen]) {
              currentGesture = GESTURE_DRAG;
              Control &c = controls[currentScreen][activeControl];
              showGuidance(c.guidance, c.guidanceColor);
              c.redraw(true);
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

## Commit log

2026-10-03 Added 3d stl files, some photos, and renamed folders
    [Desk fan housing - Fusion 360.f3d, case center bottom lid.stl, case center cover backside controller.stl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]
2026-10-03 Added README, reduced size of photo's.
    [support feet.stl]
2026-10-04 updated wiring diagram
